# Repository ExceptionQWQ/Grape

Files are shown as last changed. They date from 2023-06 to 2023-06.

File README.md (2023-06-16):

# **基于树莓派的智能物料搬运小车的系统设计**

## ***一，研究背景***
>
>        在现代物流和制造业中，物料搬运是一个不可或缺的环节。传统的物料搬运通常依赖于人工操作或传统的机械设备，但这些方法存在着一些限制和挑战。人工操作可能受到工人疲劳、人力资源限制和效率低下的问题影响。传统机械设备则可能受到固定路线和复杂环境下的机动性限制。
>        然而，随着人工智能和自动化技术的快速发展，智能物料搬运小车作为一种新型的物流解决方案已经开始崭露头角。这些小车集成了先进的感知、规划和控制系统，能够自主地感知环境、规划最优路径并执行搬运任务。智能物料搬运小车的出现为物流和制造业带来了许多机遇和改进空间。

---

## ***二，设计目的***
>        物流和制造业是现代经济中至关重要的组成部分，而物料搬运作为物流过程中不可或缺的环节，对于企业的运营效率和竞争力起着至关重要的作用。传统的物料搬运方法往往面临着一系列的挑战，为了应对这些挑战，人工智能和自动化技术成为了物流行业关注的焦点。智能物料搬运小车作为一种新兴的物流解决方案，具备了自主感知、智能规划和高效执行的能力。通过利用先进的传感器技术、路径规划算法和控制系统，智能物料搬运小车能够准确感知环境、自主规划最优路径，并在复杂的物流环境中高效地执行搬运任务。  
>        此次个性化实践，我将重点研究智能物料搬运小车的零部件的选型、建模、设计以及制作过程。

---

## ***三，零件选型***

> 1. 麦克纳姆轮  
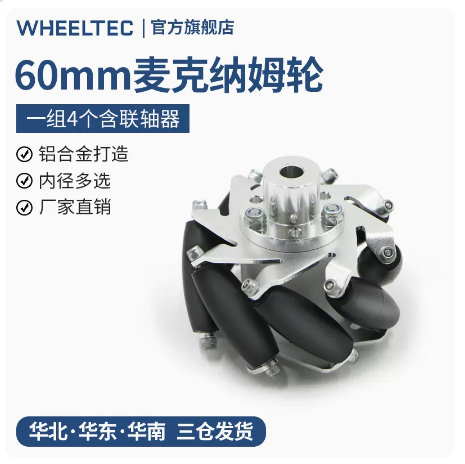
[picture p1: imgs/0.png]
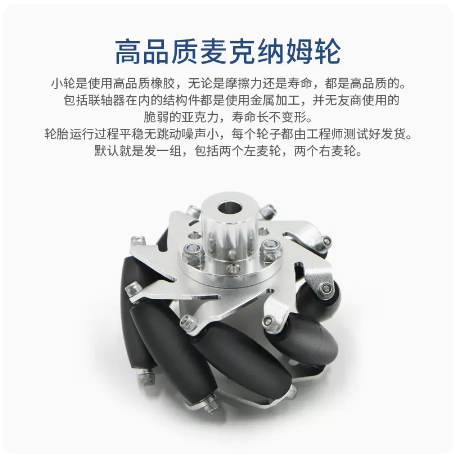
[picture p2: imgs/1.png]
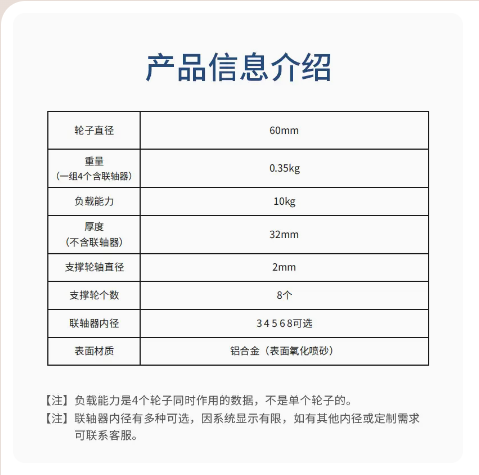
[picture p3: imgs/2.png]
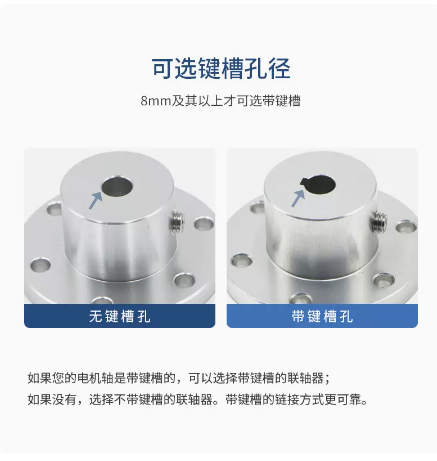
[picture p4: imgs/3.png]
>   
>    > 使用麦克纳姆轮作为智能物料搬运小车的轮胎具有以下优点：  
>    >    > 多向移动能力：麦克纳姆轮是一种特殊的全向轮，具有独特的轮胎结构和布局。它由多个斜向排列的轮辋组成，使得小车能够在不转向的情况下实现平稳的多向移动。这种设计使得小车可以自由地在水平和垂直方向上移动、旋转和平移，从而在狭小的空间中灵活操作和搬运物料。  
>    > 
>    >    > 卓越的机动性：麦克纳姆轮的布局和运动原理使得小车具有卓越的机动性。每个轮子都可以独立运动，无论是向前、向后、向左还是向右，都可以实现精确的控制。这种机动性使得小车能够轻松地避开障碍物、穿过狭窄的通道和转弯，提高了操作的灵活性和效率。  
>    > 
>    >    > 高精度定位：麦克纳姆轮的运动特性使得小车能够实现高精度的定位和操控。通过对每个轮子的独立控制，可以精确地调整和控制小车的位置和姿态。这种精度定位的能力对于准确搬运和定位物料非常重要，特别是在需要精细操作的环境中。
>
> 2. 电机驱动  
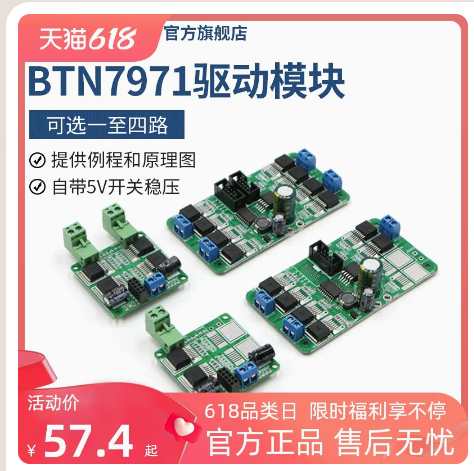
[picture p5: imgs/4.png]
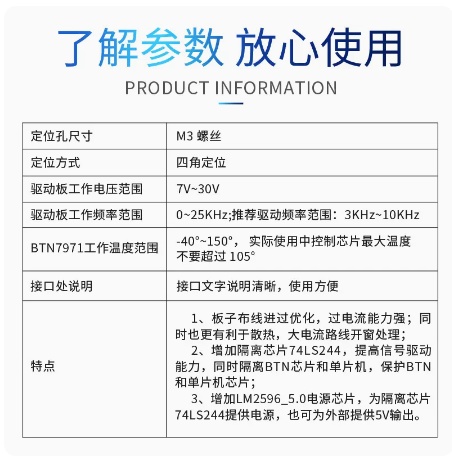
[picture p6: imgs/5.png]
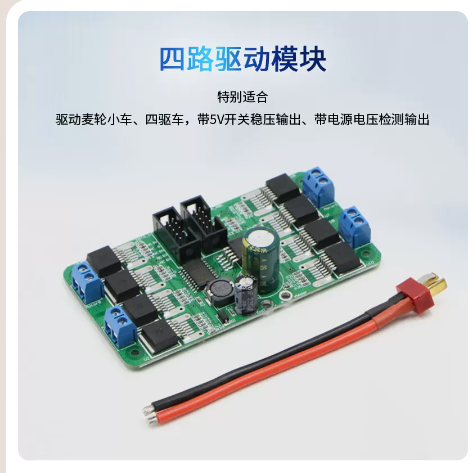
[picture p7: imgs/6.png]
> 
> 
>    > 这是一款可驱动大功率电机的电机驱动模块，具有大电流，高驱动的特点。
>
> 3. 调试下载器  
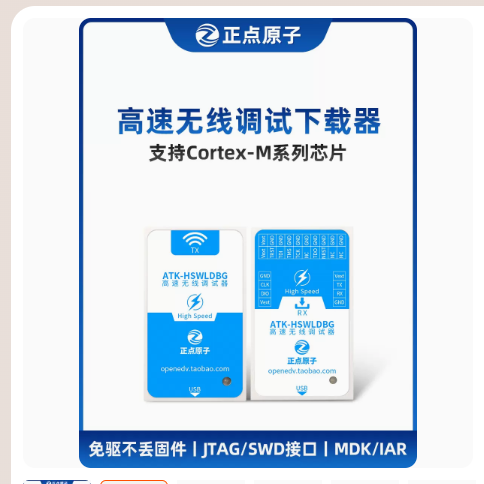
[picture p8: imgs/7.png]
> 
>    > 这款高速无线调试下载器支持仿真调试、程序下载、无线串口功能，提供20P标准JTAG借口和4P简化SWD接口，能够很大程度上帮助我调试小车。
>
> 4. 舵机  
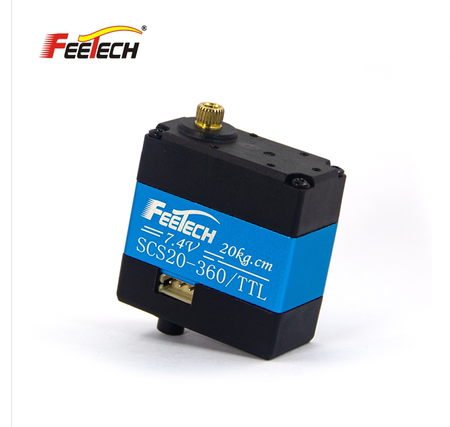
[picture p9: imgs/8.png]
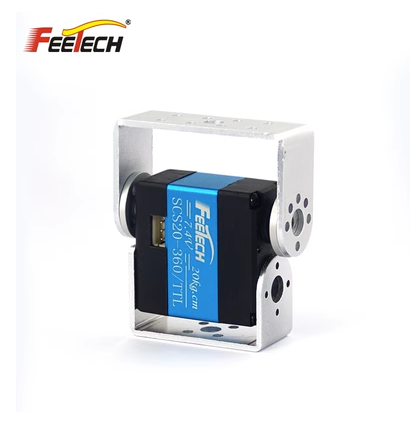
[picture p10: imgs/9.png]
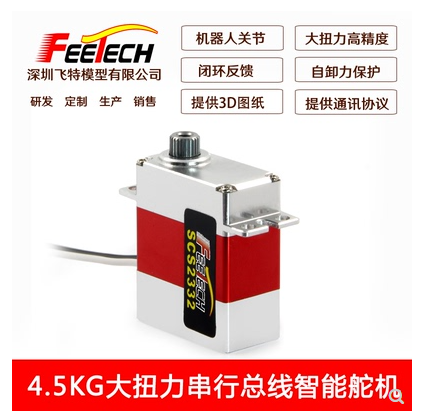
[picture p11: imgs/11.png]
> 
>    > 舵机采用飞特金属磁编码总线舵机，该产品具有以下特点，能够方便我们后期调试云台、机械臂、机械爪。  
>    >    > * 外壳采用CNC全铝合金，具有良好的导热性能。  
>    >    > * 全钢齿轮和轴承设计，强度更高，寿命更长。  
>    >    > * 采用空心杯电机作为动力源，具备无铁芯、转子、电感小、响应性好、效率高、体积小易取得大扭矩。  
>    >    > * 多圈大角度精准控制，最高精度下可以正负7圈绝对位置控制与反馈。  
>    >    > * 12位高精度无接触式磁编码传感器。  
>    >    > * 加速度启动与停止功能，可实现在行程过程中柔和运动，对齿轮有更好的保护作用。  
>    >    > * 支持4种工作模式，分别是位置模式、速度闭环电机模式、速度开环电机模式、步进模式。  
>    >    > * 一键校准中位，360度角度任意安装，非常方便安装，可提升生产效率和降低维护成本。  
>    >    > * 过载保护。  
>    >    > * 过热保护。  
>    >    > * 实时反馈。  
>    >    > * 角度限位。  
>    >    > * 最大扭矩限制。  
>    >    > * PID比例系统调节。  
>    >    > * 多个舵机串联控制。  
> 5. 打印耗材  
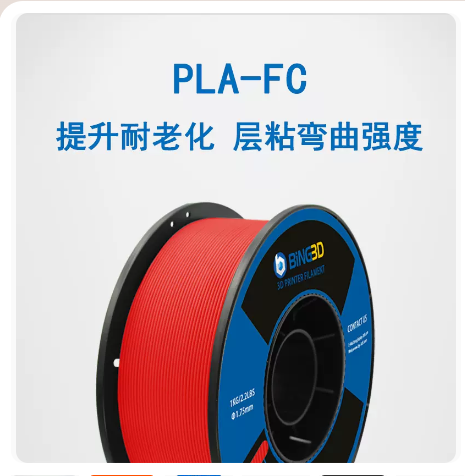
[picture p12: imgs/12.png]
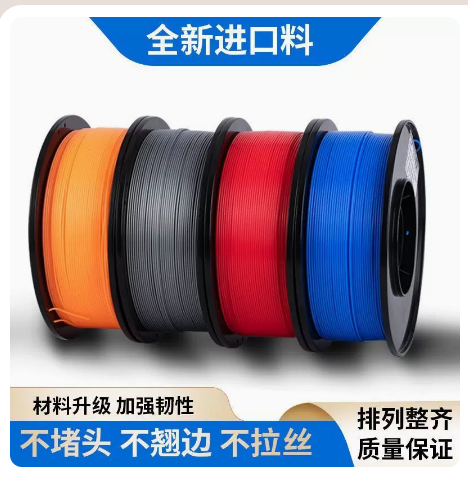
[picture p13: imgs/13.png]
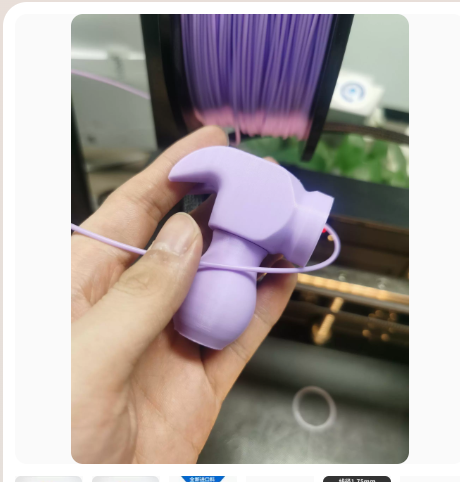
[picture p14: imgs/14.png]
> 
>    > 机械臂机械爪和外壳部分，我计划采用3D打印，我使用的必应PLA-FC材料，与传统PLA材料相比，PLA-FC的韧性与抗冲击强度更优异，使其打印成品具备的物理性能广泛应用于小批量打印工业件，并且它价格便宜，Raise3D官方1kg耗材需要199元，而必应只需要39元。
> 6. 碳纤维板  
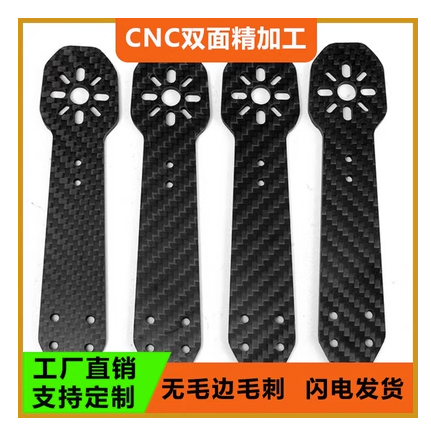
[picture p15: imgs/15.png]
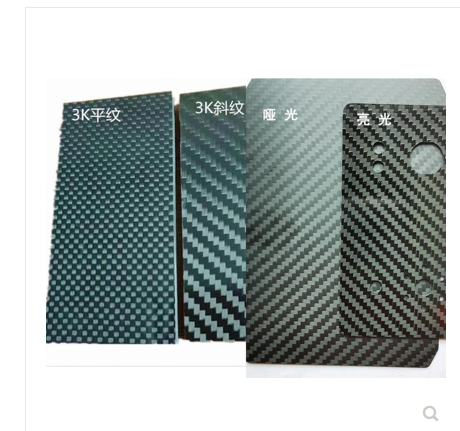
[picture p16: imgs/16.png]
> 
>    > 使用碳纤维版作为智能物料搬运小车的底盘具有轻量化、高强度和刚度、抗腐蚀性和耐久性、良好的振动和噪音阻尼、美观性和设计自由度等优点。这些优势使得碳纤维底盘成为一种理想的选择，能够提升小车的性能、稳定性和寿命，为智能物料搬运小车的应用带来更好的效果和体验。
> 7. 电源模块  
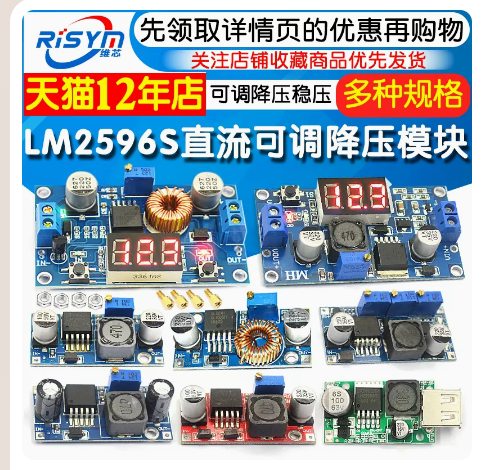
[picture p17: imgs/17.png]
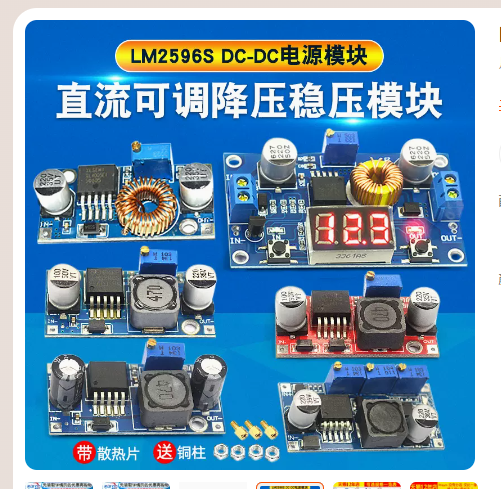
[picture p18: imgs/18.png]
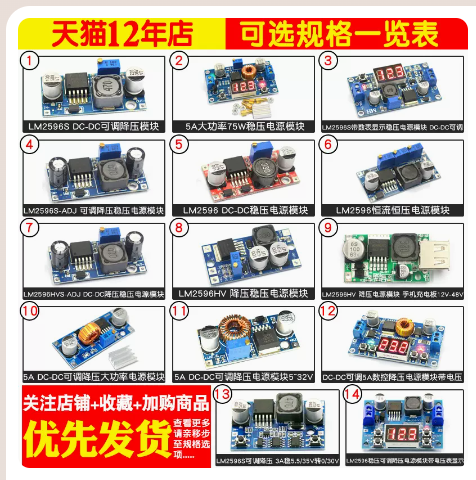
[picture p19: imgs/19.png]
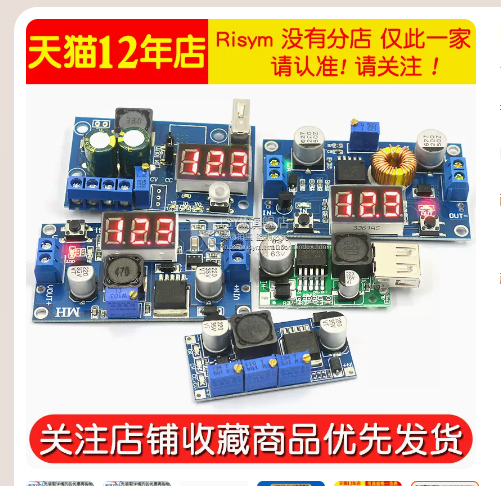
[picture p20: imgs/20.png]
> 
>    > 我计划采用3个5A大功率75W稳压电源模块，支持4～38V的宽电压输入范围，一块负责提供5V电压，给树莓派、单片机、模块供电，一块负责提供7.4V电压，给舵机供电，最后一块负责提供12V电压，给电机驱动供电。
> 8. 电池  
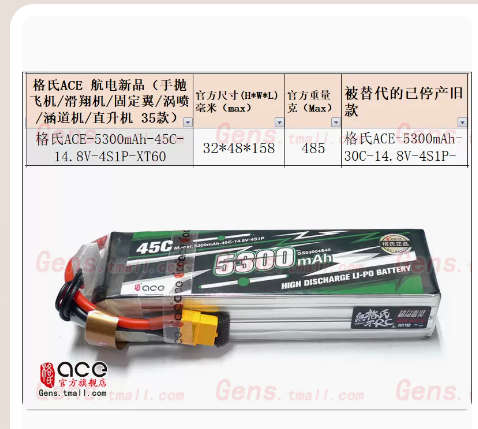
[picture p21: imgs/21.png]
> 
>    > 格氏5300mah 4s 14.8V 30C电池，持续放电159A（瞬间318A），动力强劲。
> 9. 电机  
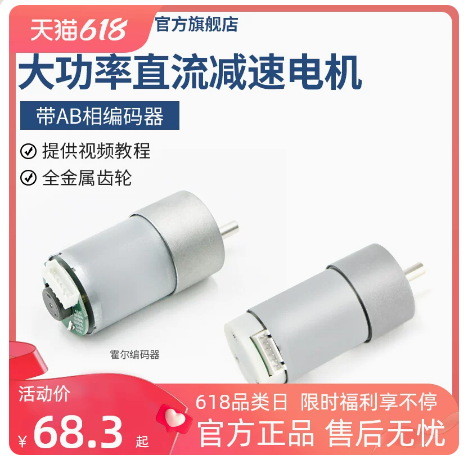
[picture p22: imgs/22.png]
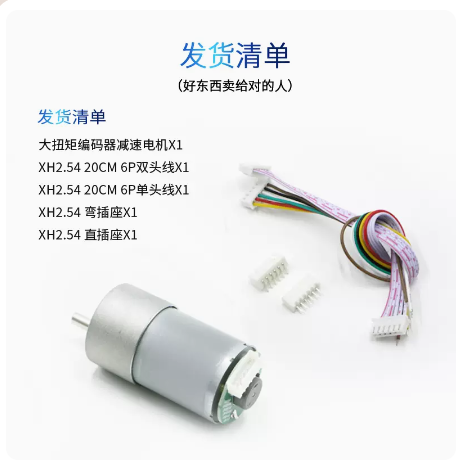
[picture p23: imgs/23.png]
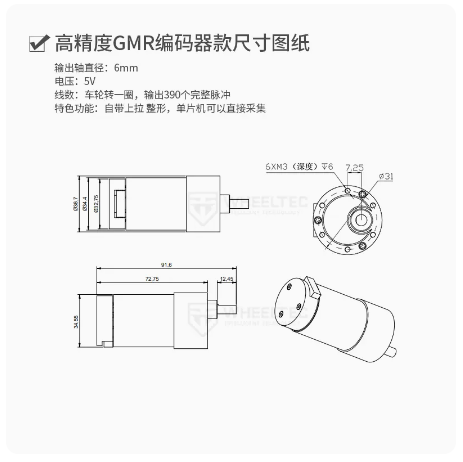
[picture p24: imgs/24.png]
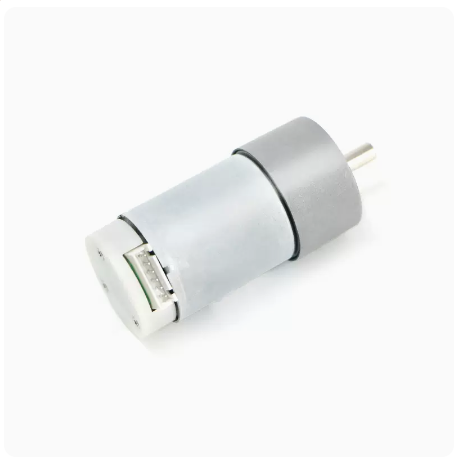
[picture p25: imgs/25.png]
> 
>    > WHEEL TEC的MG540大功率直流减速电机（高精度GMR编码器款），GMR编码器是霍尔编码器精度的38倍，在低速情况下表现优异。
> 10. 激光雷达  
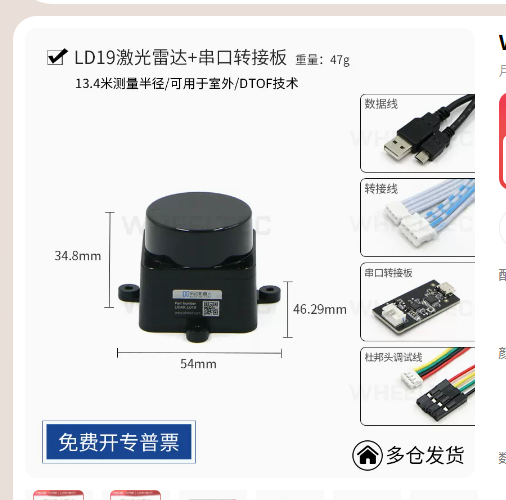
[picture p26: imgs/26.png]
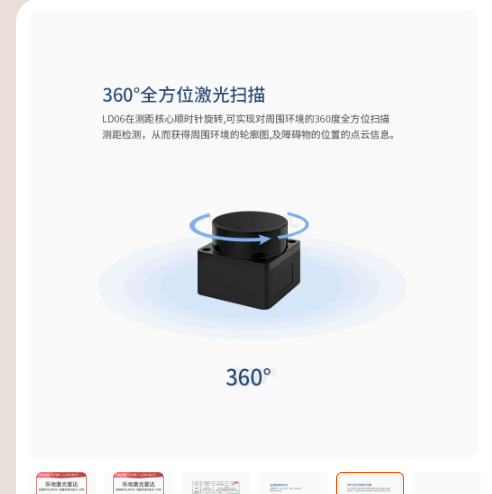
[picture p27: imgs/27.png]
> 
>     > 基于TOF原理的LD19激光雷达可抗强光，可有效避免强光照干扰，可抵抗30000Lux的强光环境，可实现室内外高频高精度的距离测量及精准建图。LD19测量半径可以达到13.4m，扫描频率10HZ，采样频率4500次/s。内置无刷电机相比传统的有刷电机具有更高的效能，寿命更长。
> 11. 深度相机  
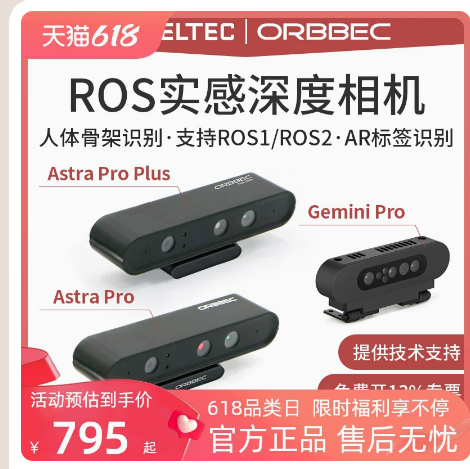
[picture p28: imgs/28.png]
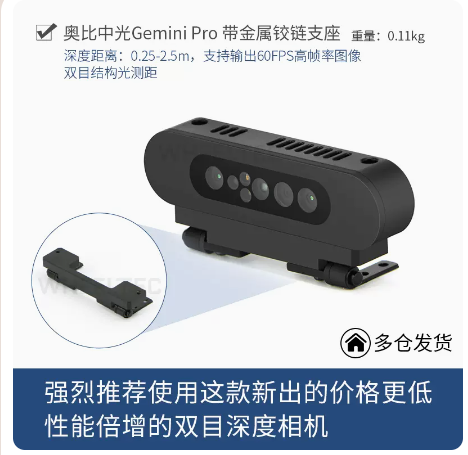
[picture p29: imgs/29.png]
> 
>     > Gemini Pro相机基于双目结构光（红外投影）测距原理，高达8米深度测距，特别适合机器人三维环境重建，提高环境建模效率，测量盲区低至0.25米，特别适用于近距离测量，广泛应用于机器人末端执行器定位等应用场景。Gemini Pro使用了D435i等国际知名相机惯用的成熟双目架构，支持在室外场景使用。它带有可以自由旋转的铰链支座，安装简单，方便调整相机视角，金属加工，更加稳固耐用。
> 12. 树莓派  
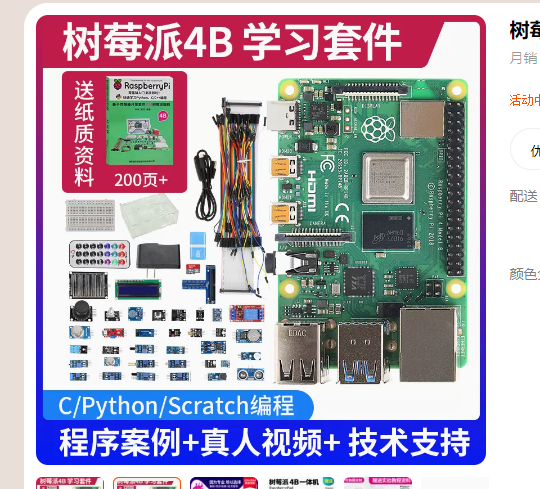
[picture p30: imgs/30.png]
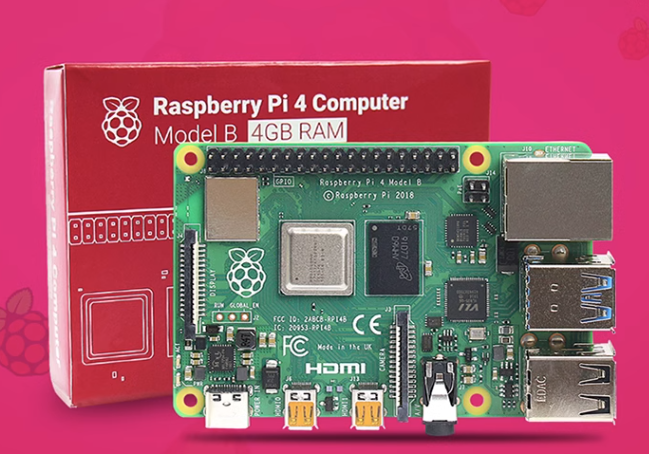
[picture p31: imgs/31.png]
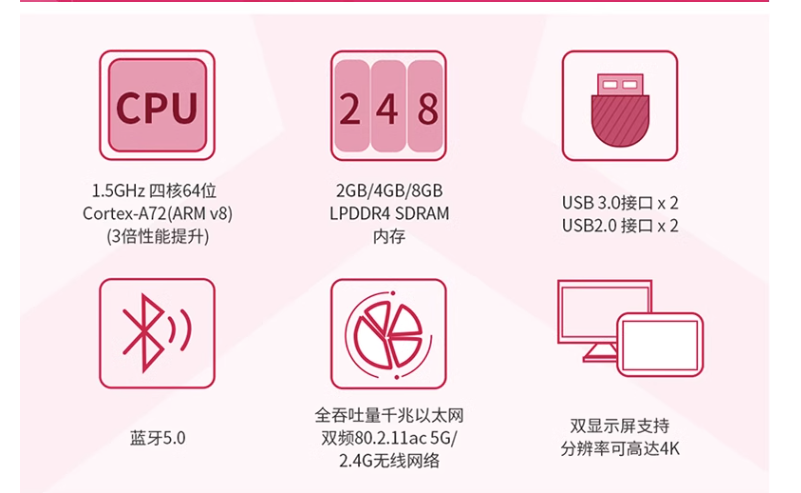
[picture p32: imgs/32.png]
> 
>     > 树莓派是一款基于ARM架构的单板计算机，具有较强的计算和处理能力。它采用高性能的处理器和足够的内存，能够处理复杂的算法和任务，支持实时控制和决策。这使得树莓派能够实现复杂的路径规划、感知处理和决策算法，提高智能物料搬运小车的智能化水平。树莓派提供了丰富的接口和扩展插槽，包括GPIO、USB、HDMI等接口，可以连接各种传感器、执行器和外部设备。这使得树莓派可以方便地与硬件组件进行通信和控制，实现与激光雷达、下位机、摄像头等设备的无缝集成。树莓派具有广泛的开发者社区和大量的开源软件资源，提供了丰富的开发环境和工具支持。开发者可以利用Python、C++等编程语言进行开发，并借助各种开源库和工具快速实现功能。这降低了开发门槛，加快了系统开发和调试的速度。
> 13. 无线网卡  
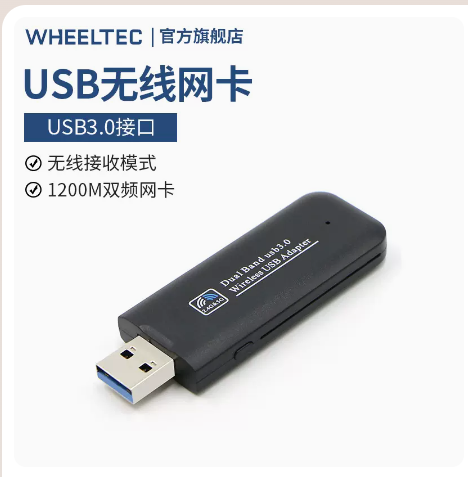
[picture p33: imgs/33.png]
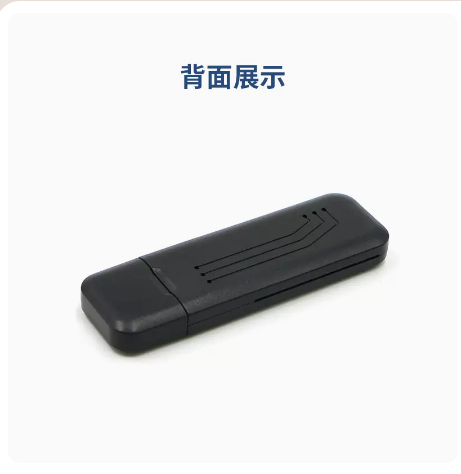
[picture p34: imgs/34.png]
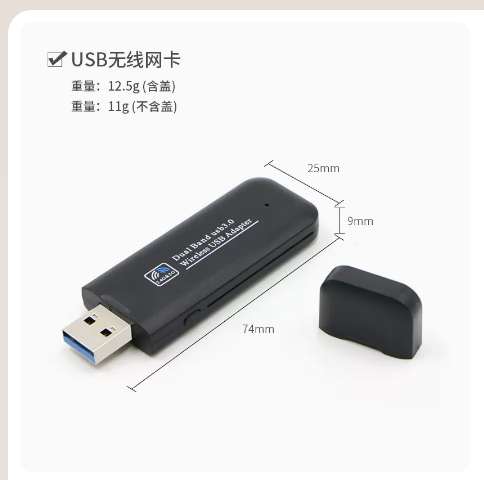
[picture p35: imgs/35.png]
> 
>     > 鉴于树莓派自带的无线能力弱，我外置了一款USB3.0的无线网卡。
> 14. USB摄像头  
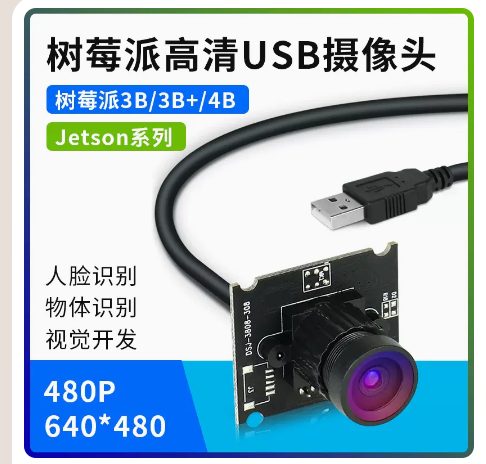
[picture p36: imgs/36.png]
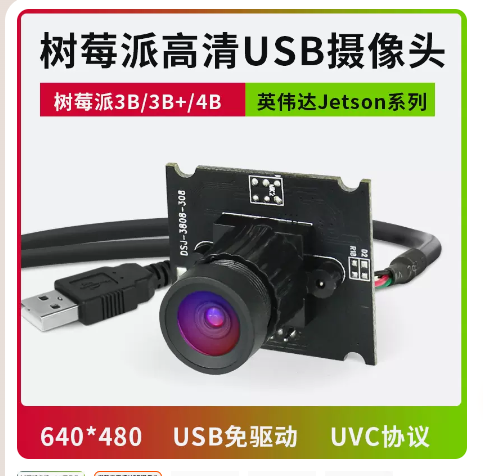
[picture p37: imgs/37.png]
> 
>     > 末端执行器采用便宜的USB摄像头，可以实现物料识别与定位。
> 15. STM32  
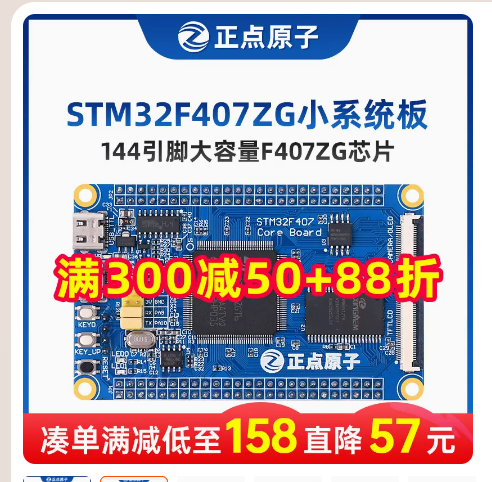
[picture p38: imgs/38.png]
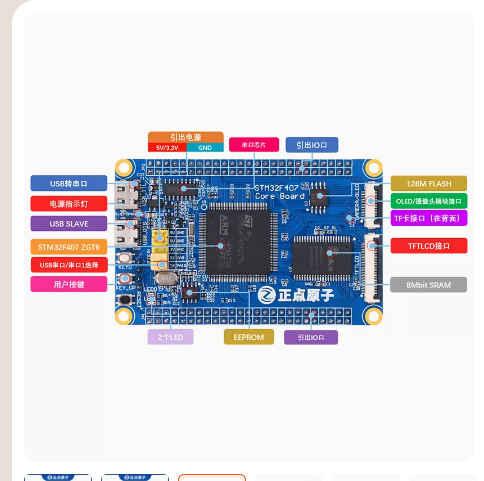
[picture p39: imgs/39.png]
> 
>     > 采用高性能的STM32F407最小系统板作为下位机，实现运动控制算法。
> 16. 惯性导航模块  
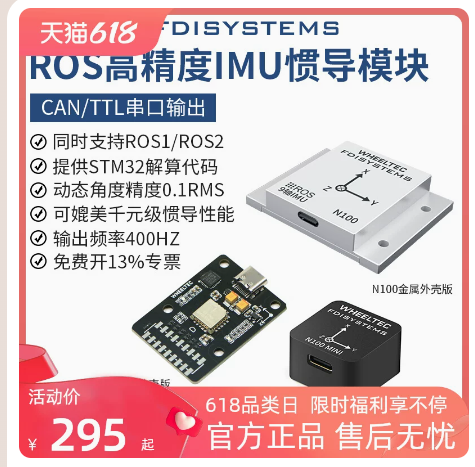
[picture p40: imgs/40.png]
> 
>     > N100惯导模块具备丰富的数据输出，支持三轴加速度、三轴陀螺仪、三轴磁力计、三轴欧拉角、四元数、方向余弦矩阵、速度、位置输出，自带卡尔曼融合算法。

---

## ***四，PCB板设计***

> 1. 绘制原理图
>    > * STM32F407  
>    >    >  
>    > * 电机接口  
>    >    >   
>    > * 电机驱动接口  
>    >    >   
>    > * 外部传感器接口  
>    >    >   
> 2. 绘制PCB
>    >  

---

## ***四，零件建模***
> 1. 惯性导航模块  
>    > 
> 2. 37电机支架  
>    > 
> 3. DC电源模块 
>    > 
> 4. SCS125舵机  
>    > 
> 5. SCS2332舵机  
>    > 
> 6. STS3020舵机  
>    > 
> 7. USB摄像头  
>    > 
> 8. 云台  
>    > 
> 9. 舵机支架  
>    >  
> 10. BTN7971四路驱动  
>     > 
> 11. 舵盘  
>     >  
> 12. TTL信号转换板  
>     > 
> 13. 机械臂  
>     > 
> 14. 树莓派  
>     > 
> 15. 联轴器  
>     > 
> 16. 深度相机  
>     > 
> 17. 激光雷达  
>     > 
> 18. 机械爪  
>     > 
> 19. 电机  
>     > 
> 20. 船型开关  
>     > 
> 21. 散热风扇  
>     > 
> 22. 麦克纳姆轮  
>     > 

----

## ***五，小车结构设计***

> * 设计底盘2  
>     > 
> * 安装4个直流减速电机  
>     > 
> * 安装4个麦克纳姆轮  
>     > 
> * 设计底盘1  
>     > 
> * 装配底盘1  
>     > 
> * 给底盘1开4个矩形孔  
>     > 
> * 设计底盘3  
>     > 
> * 装配底盘3  
>     > 
> * 开一个放置云台的孔  
>     > 
> * 放置云台  
>     > 
> * 设计放置电池的位置  
>     > 
> * 放置电池  
>     > 
> * 设计放置电机驱动板的位置  
>     > 
> * 放置电机驱动板  
>     > 
> * 设计放置电源模块的位置  
>     > 
> * 放置电源模块  
>     >   
> * 放置2个激光雷达  
>     >   
> * 放置TTL信号转换板  
>     >   
> * 放置惯性导航模块  
>     >   
> * 放置树莓派  
>     >   
> * 放置深度相机  
>     >   
> * 放置下位机控制板  
>     >   
> * 完成外壳1设计  
>     >   
> * 完成外壳2设计  
>     > 
>     > 
>     >   
> * 设计机械臂  
>     > 
>     > 
>     > 
>     >   
> * 放置机械爪  
>     >   
> * 完成运动分析  
>     >   

## ***六，物流小车组装***


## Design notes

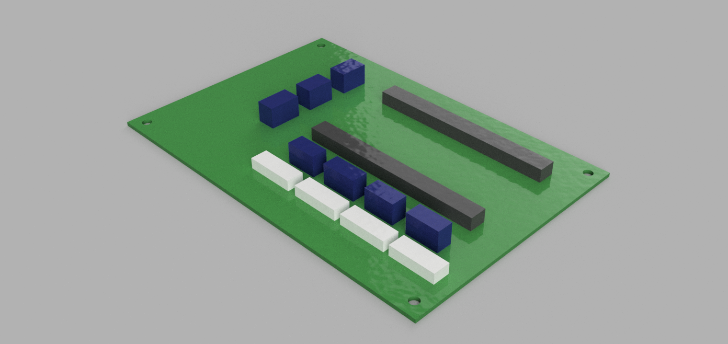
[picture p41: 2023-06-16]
imgs/渲染/pcb v3.png

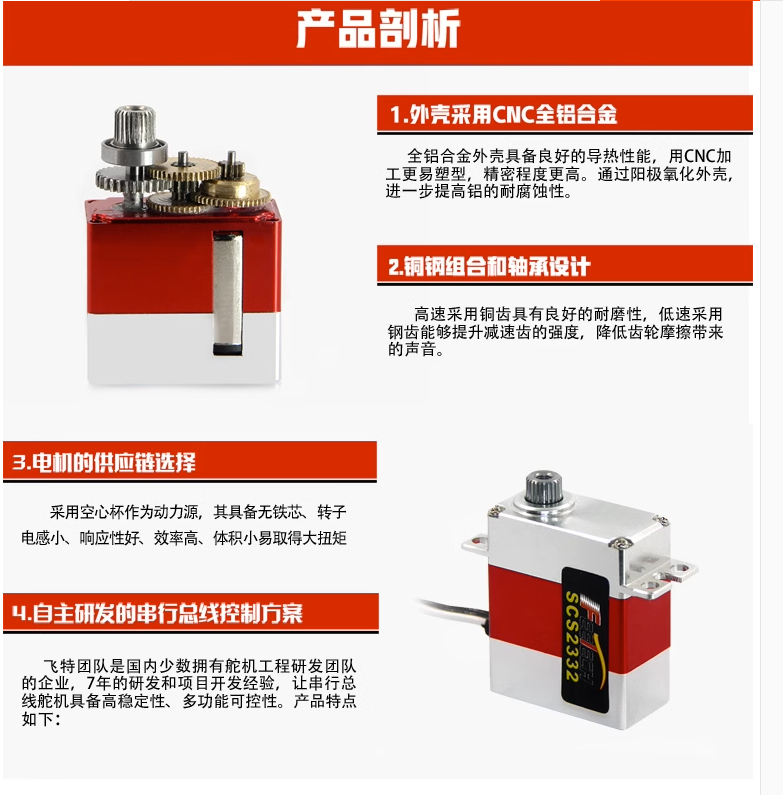
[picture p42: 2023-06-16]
imgs/选型/舵机/屏幕截图 2023-06-11 194429.png

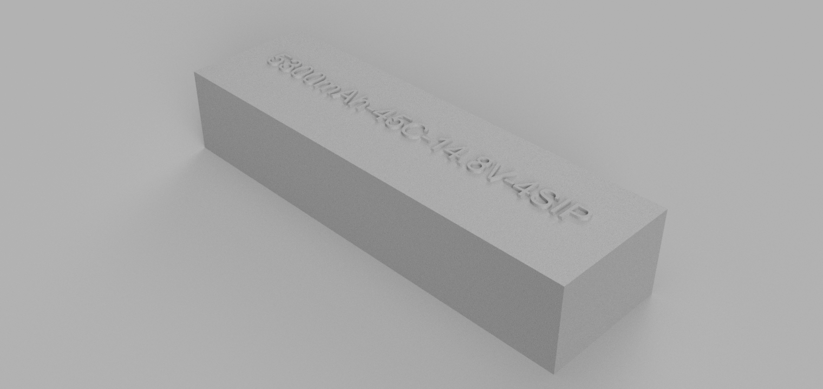
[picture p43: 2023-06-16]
imgs/渲染/格氏电池 v2.png

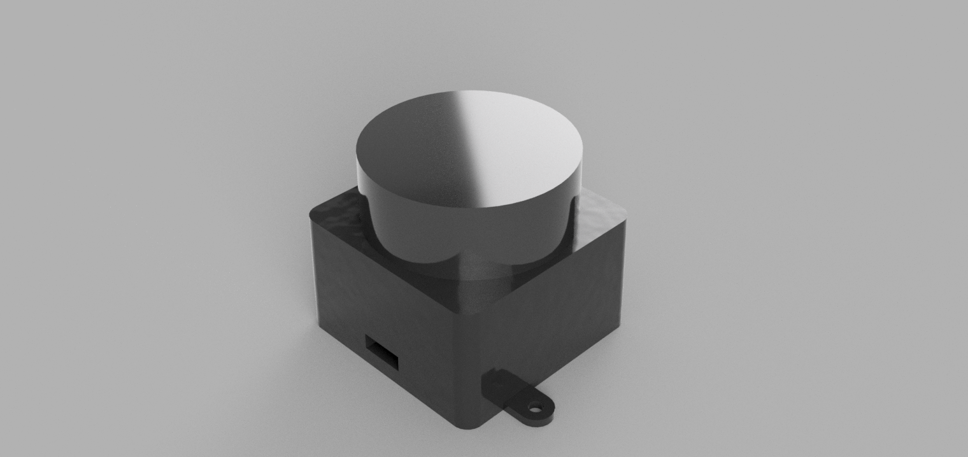
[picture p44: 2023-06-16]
imgs/渲染/LD19激光雷达 v2.png

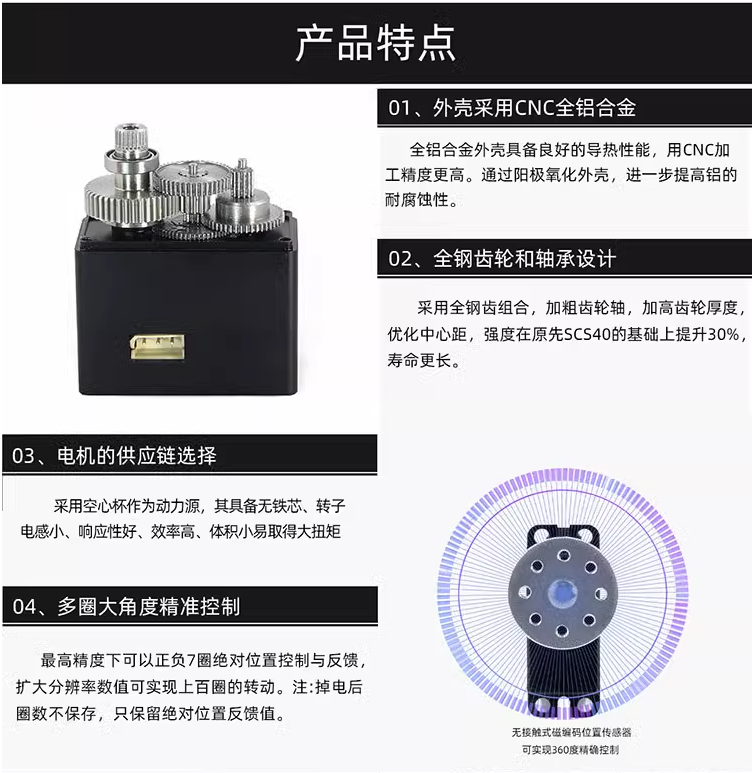
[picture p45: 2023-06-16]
imgs/选型/舵机/屏幕截图 2023-06-11 194345.png

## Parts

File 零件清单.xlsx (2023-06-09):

名称 | 型号 | 单价 | 数量 | 购买链接 | 备注
麦克纳姆轮 | 直径60mm 安装孔径6mm不带键槽*4个 | 219 | 1 | https://m.tb.cn/h.UCVZ0lf?tk=cFMZdqj3pVL
MG540大扭矩编码器减速电机 | 高精度GMR编码器款+支架 | 102.8 | 4 | https://m.tb.cn/h.UCVbmNc?tk=RwkEdqj4uUE
多路BTN7971 | 四路驱动模块 | 218 | 1 | https://m.tb.cn/h.UCV1f7k?tk=JmL6dqjflCD
惯导模块IMU | N100带金属外壳 | 388 | 1 | https://m.tb.cn/h.UBOkcWQ?tk=PZUZdqj5E9F
DC-DC直流可调降压稳压电源 | 5A大功率75W稳压电源模块 | 26.06 | 3 | https://m.tb.cn/h.UyKMBMc?tk=ESjidqjgyh9
船型开关 | KCD4 4脚2档红灯 铜脚（2个） | 2.67 | 1 | https://m.tb.cn/h.UBOlMuA?tk=lD7qdqj6hWA
格氏ACE 新航电池 | 5300mAh 45C 4S xt60 | 428 | 1 | https://m.tb.cn/h.UBON5C1?tk=DiTSdqjhGIg
信号转换板 | 宝蓝色 信号转化板 | 40 | 1 | https://m.tb.cn/h.UBOn7Pn?tk=YumOdqjhIBK
双轴舵机 | 蓝色 ST3020带支架 | 120 | 3 | https://m.tb.cn/h.UBOn7Pn?tk=YumOdqjhIBK
金属40kg360度单轴舵机 | 黑色 ST-3046-C001 单轴 | 448 | 1 | https://m.tb.cn/h.UCVerpt?tk=kL5Bdqj7Olc
飞特4.5kg小舵机 | SCS2332/270度转动 | 148 | 2 | https://m.tb.cn/h.UCBpQ1x?tk=PbcPdqjidTB
正点原子STM32F407ZGT6小系统板 | 焊排针 | 218 | 1 | https://m.tb.cn/h.UBOLk6I?tk=8LTGdqj8JmE
正点原子高速无线调试器 | 发射端+大接收端 | 368 | 1 | https://m.tb.cn/h.UBOpNEC?tk=zPCldqj8AF6
树莓派4B | 树莓派4B/8G单独主板 | 1059 | 1 | https://m.tb.cn/h.UBOpH1S?tk=w1OHdqj8wiv
树莓派jetson免驱USB摄像头 | USB摄像头 | 49 | 1 | https://m.tb.cn/h.UCBJ9R2?tk=QJ5EdqjQE0O
树莓派4代CPU散热器 | 卧式散热器（白色） | 105 | 1 | https://m.tb.cn/h.UyKGgFU?tk=PCMfdqj9McP
无线网卡千兆高速免驱动 | USB无线网卡 | 79 | 1 | https://m.tb.cn/h.UCVTKkr?tk=127odqj9HT6
激光雷达 | LD19激光雷达+串口转接板 | 549 | 2 | https://m.tb.cn/h.UCVTHbn?tk=D3pbdqjkewS
深度相机摄像头 | 【双目结构光】奥比中光Gemini Pro | 1190 | 1 | https://m.tb.cn/h.UyKFkdo?tk=C3BhdqjkLWe
必应3d打印耗材pla-f复合材料 | PLA-FC 浅紫色 1KG | 39 | 5 | https://m.tb.cn/h.UBOI5r3?tk=oOl1dqjlP1W
华秋PCB打样 | 最终价格请先联系客服报价 | 92 | 1 | https://m.tb.cn/h.UCV6yi7?tk=EZppdqjlV4G
碳纤维板加工 | 黑色/平纹/哑光 | 700 | 1 | https://m.tb.cn/h.UyKExnh?tk=LEaZdqjOYlh
BB响 | BX100 低压报警器 | 7.2 | 1 | https://m.tb.cn/h.UyKwnkc?tk=DJCVdqjlwpF

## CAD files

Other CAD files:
3D模型/37GB电机支架 v2.f3d
3D模型/9轴IMU v2.f3d
3D模型/DC模块 v2.f3d
3D模型/LD19激光雷达 v2.f3d
3D模型/MG540直流减速电机（GMR） v8.f3d
3D模型/SCS125舵机 v2.f3d
3D模型/SCS2332舵机 v2.f3d
3D模型/STS3020双轴舵机 v1.f3d
3D模型/USB摄像头 v2.f3d
3D模型/pcb v3.f3d
3D模型/云台 v10.f3z
3D模型/双轴舵机支架1 v3.f3d
3D模型/双轴舵机支架2 v2.f3d
3D模型/四路驱动模块 v2.f3d
3D模型/大臂 v4.f3d
3D模型/小臂 v3.f3d
3D模型/小舵机舵盘 v2.f3d
3D模型/总线舵机信号转换版 v2.f3d
3D模型/显示屏 v2.f3d
3D模型/标准舵机 v4.f3d
3D模型/树莓派 v2.f3d
3D模型/格氏电池 v2.f3d
3D模型/法兰联轴器 v3.f3d
3D模型/深度相机 v2.f3d
3D模型/爪子 v6.f3z
3D模型/爪子右 v4.f3d
3D模型/爪子左 v4.f3d
3D模型/船型开关（红） v4.f3d
3D模型/船型开关（绿） v3.f3d
3D模型/金属舵盘 v4.f3d
3D模型/风扇 v1.f3d
3D模型/麦克纳姆轮A v5.f3d
3D模型/麦克纳姆轮B v9.f3d

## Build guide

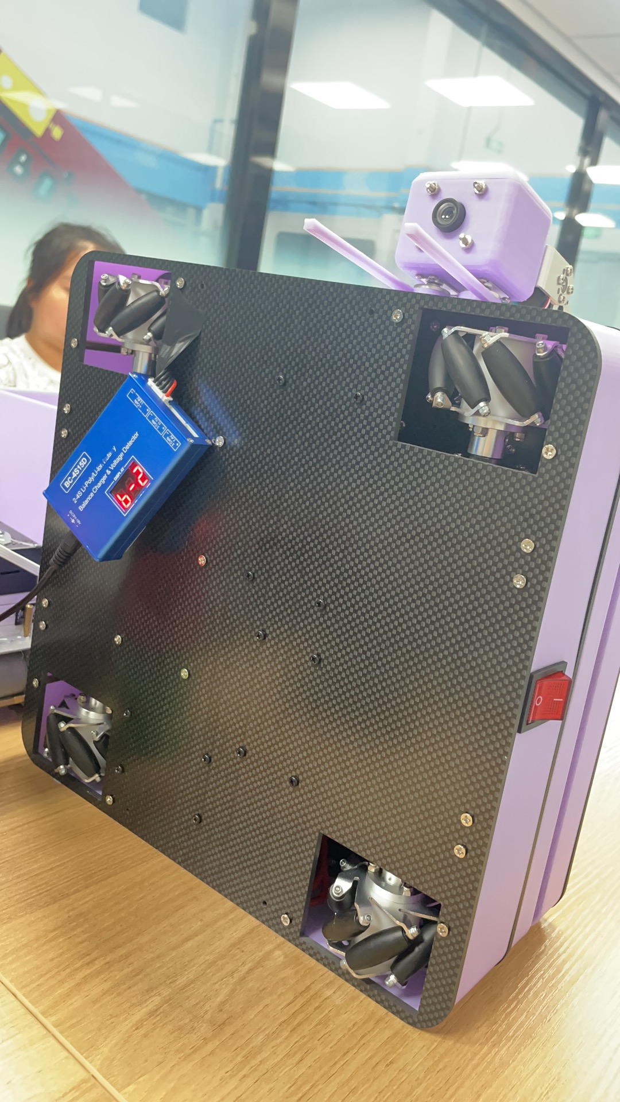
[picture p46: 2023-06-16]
imgs/组装/D7C8EA0B-1885-40CE-9DB8-34D4BC48AEBF.jpeg

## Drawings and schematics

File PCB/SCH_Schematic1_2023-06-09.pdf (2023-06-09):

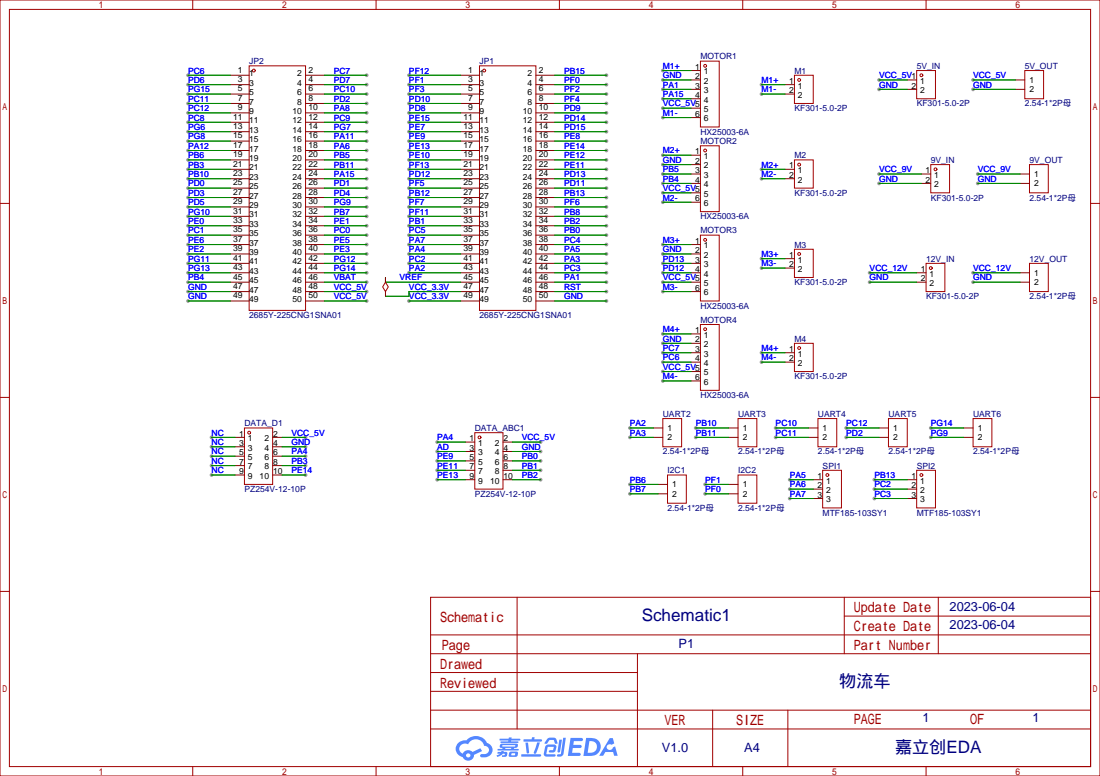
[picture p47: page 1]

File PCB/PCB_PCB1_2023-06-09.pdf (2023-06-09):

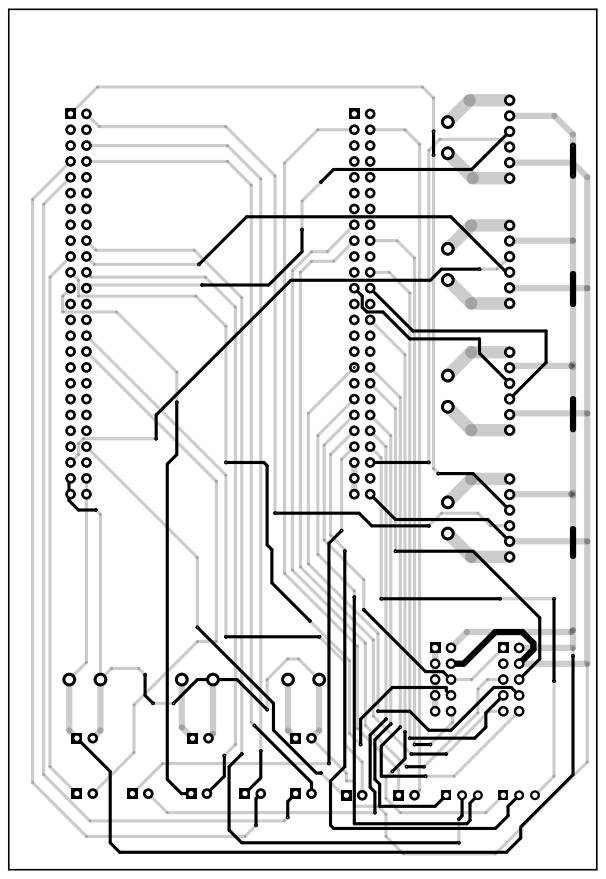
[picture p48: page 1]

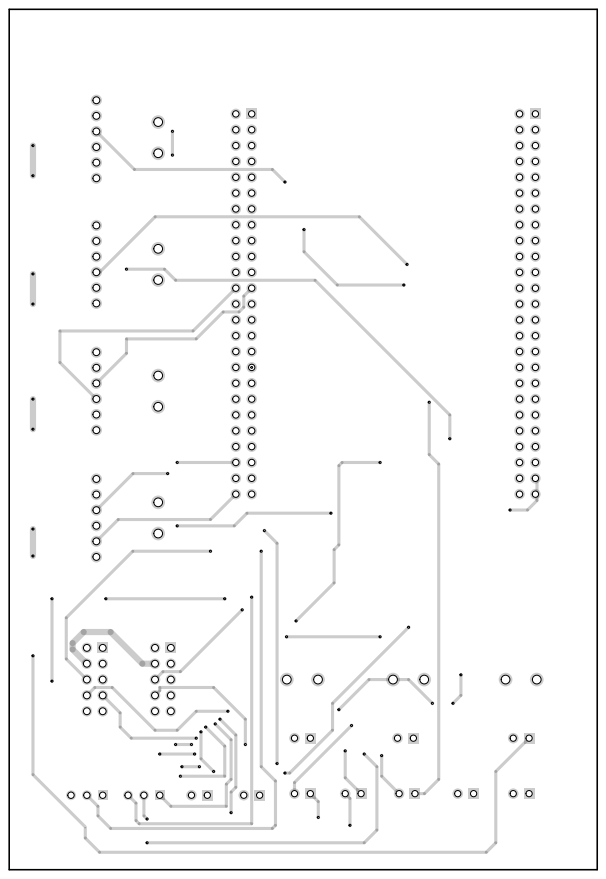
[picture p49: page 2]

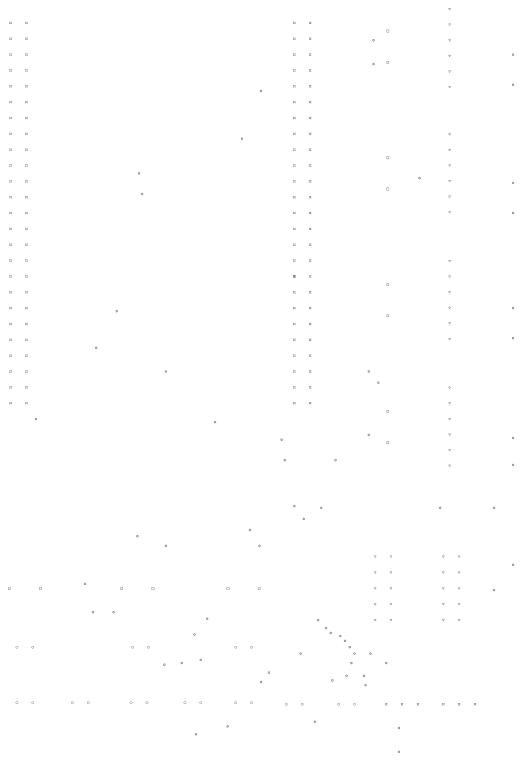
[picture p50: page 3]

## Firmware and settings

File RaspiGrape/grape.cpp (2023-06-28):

#include "grape.h"
#include "robot.h"
#include "servo.h"



struct ArmInfo
{
    double len;
    double radian;
};


using ArmList = std::vector<ArmInfo>;

ArmList SolveArm3DH(double len1, double len2, double len3, double xPos, double yPos)
{
    if (fabs(xPos) < 0.001) xPos = 0.001;
    double len = std::sqrt(std::pow(xPos, 2) + std::pow(yPos, 2));
    if (len > len1 + len2) return ArmList{}; //无解
    double r4 = std::acos((std::pow(len1, 2) + std::pow(len2, 2) - std::pow(len, 2)) / (2 * len1 * len2));
    double r5 = std::atan(yPos / xPos);
    if (xPos < 0 && yPos > 0) {
        r5 += PI;
    }
    std::cout << r4 << std::endl;
    double r2 = r4 - PI;
    double r3 = std::asin(len2 * std::sin(r4) / len);
    double r1 = r3 + r5;
    return ArmList{{len1, r1}, {len2, r2}, {len3, -(r1 + r2)}};
}

// SERVO_TAG_L1 = 2, //0-3050, 90-2050
//     SERVO_TAG_L2 = 3, //0-2150, 90-3150
//     SERVO_TAG_L3 = 4, //0-1950, 90-2950
//     SERVO_TAG_ClawL = 5, //0-, 90-
//     SERVO_TAG_ClawR = 6, //0-, 90-


void SetL1Angle(double angle)
{
    std::cout << "l1: " << angle << std::endl;
    if (angle < 0 || angle > 150) return ;
    int pos = 3050;
    double add = 1000.0 / 90.0 * angle;
    pos += -add;
    SetServoPos(SERVO_TAG_L1, pos, 800);
}

void SetL2Angle(double angle)
{
    std::cout << "l2: " << angle << std::endl;
    if (angle < -150 || angle > 90) return ;
    int pos = 2150;
    double add = 1000.0 / 90.0 * angle;
    pos += add;
    SetServoPos(SERVO_TAG_L2, pos, 800);
}

void SetL3Angle(double angle)
{
     std::cout << "l3: " << angle << std::endl;
    if (angle < -90 || angle > 90) return ;
    int pos = 1950;
    double add = 1000.0 / 90.0 * angle;
    pos += add;
    SetServoPos(SERVO_TAG_L3, pos, 800);
}


int main()
{
    Robot_Init();
    Robot_Start();
    Servo_Init();
    Servo_Start();

    sleep(1);

    SetL1Angle(0);
    SetL2Angle(0);
    SetL3Angle(0);
    UpdateServoPos();

    sleep(3);

    double len1 = 165, len2 = 185, len3 = 55;
    double xPos = 340, yPos = 0;
    for (int i = 0; i < 80; ++i) {
        xPos -= 1;
        ArmList armList = SolveArm3DH(len1, len2, len3, xPos, yPos);
        if (armList.size() != 0) {
            SetL1Angle(180 / PI * armList[0].radian);
            SetL2Angle(180 / PI * armList[1].radian);
            SetL3Angle(180 / PI * armList[2].radian);
            UpdateServoPos();
        }
        usleep(10000);
    }
    for (int i = 0; i < 160; ++i) {
        yPos += 1;
        ArmList armList = SolveArm3DH(len1, len2, len3, xPos, yPos);
        if (armList.size() != 0) {
            SetL1Angle(180 / PI * armList[0].radian);
            SetL2Angle(180 / PI * armList[1].radian);
            SetL3Angle(180 / PI * armList[2].radian);
            UpdateServoPos();
        }
        usleep(10000);
    }
    for (int i = 0; i < 130; ++i) {
        xPos -= 1;
        ArmList armList = SolveArm3DH(len1, len2, len3, xPos, yPos);
        if (armList.size() != 0) {
            SetL1Angle(180 / PI * armList[0].radian);
            SetL2Angle(180 / PI * armList[1].radian);
            SetL3Angle(180 / PI * armList[2].radian);
            UpdateServoPos();
        }
        usleep(10000);
    }


    // SetServoPos(SERVO_TAG_YUNTAI, 1450, 300);
    // SetServoPos(SERVO_TAG_L1, 3050, 300);
    // SetServoPos(SERVO_TAG_L2, 2150, 300);
    // SetServoPos(SERVO_TAG_L3, 1950, 300);
    // UpdateServoPos();

    while (true) {
        sleep(1);
        GetServoPos(SERVO_TAG_YUNTAI);
        GetServoPos(SERVO_TAG_L1);
        GetServoPos(SERVO_TAG_L2);
        GetServoPos(SERVO_TAG_L3);
        GetServoPos(SERVO_TAG_ClawL);
        GetServoPos(SERVO_TAG_ClawR);

        std::cout << "yuntai: " << servoInfo.yuntaiPos << std::endl;
        std::cout << "l1: " << servoInfo.l1Pos << std::endl;
        std::cout << "l2: " << servoInfo.l2Pos << std::endl;
        std::cout << "l3: " << servoInfo.l3Pos << std::endl;
        std::cout << "clawL: " << servoInfo.clawLPos << std::endl;
        std::cout << "clawR: " << servoInfo.clawRPos << std::endl;
        std::cout << "#############################################" << std::endl;
    }
    

    while (true) {
        char ch;
        std::cin >> ch;
        double speed;
        switch (ch) {
            case 'x':
                std::cin >> speed;
                Robot_MoveX(speed);
            break;
            case 'y':
                std::cin >> speed;
                Robot_MoveY(speed);
            break;
            case 'z':
                std::cin >> speed;
                Robot_MoveZ(speed);
            break;
            case 's':
                Robot_Stop();
            break;


            default:

            break;
        }
    }

    return 0;
}

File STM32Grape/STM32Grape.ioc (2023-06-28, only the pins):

Mcu.UserName=STM32F407ZGTx
PA1.Signal=S_TIM2_CH2
PA10.Signal=USART1_RX
PA13.Signal=SYS_JTMS-SWDIO
PA14.Signal=SYS_JTCK-SWCLK
PA15.Signal=S_TIM2_CH1_ETR
PA4.GPIO_Label=MOTOR_EN
PA4.Signal=GPIO_Output
PA9.Signal=USART1_TX
PB0.GPIO_Label=MOTOR1_DIRECTION
PB0.Signal=GPIO_Output
PB1.GPIO_Label=MOTOR2_DIRECTION
PB1.Signal=GPIO_Output
PB2.GPIO_Label=MOTOR3_DIRECTION
PB2.Signal=GPIO_Output
PB3.GPIO_Label=MOTOR4_DIRECTION
PB3.Signal=GPIO_Output
PB4.Signal=S_TIM3_CH1
PB5.Signal=S_TIM3_CH2
PC6.Signal=S_TIM8_CH1
PC7.Signal=S_TIM8_CH2
PD12.Signal=S_TIM4_CH1
PD13.Signal=S_TIM4_CH2
PE11.Signal=S_TIM1_CH2
PE13.Signal=S_TIM1_CH3
PE14.Signal=S_TIM1_CH4
PE9.Signal=S_TIM1_CH1
PH0-OSC_IN.Signal=RCC_OSC_IN
PH1-OSC_OUT.Signal=RCC_OSC_OUT

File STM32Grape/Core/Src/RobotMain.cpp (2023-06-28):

#include "RobotMain.h"


RDK::EncodingMotor encodingMotor1;
RDK::EncodingMotor encodingMotor2;
RDK::EncodingMotor encodingMotor3;
RDK::EncodingMotor encodingMotor4;
RDK::MecanumMotion mecanumMotion;


void Motor1Callback(double pwm)
{
    if (pwm > 0) {
        __HAL_TIM_SET_COMPARE(&htim1, TIM_CHANNEL_1, pwm);
        HAL_GPIO_WritePin(MOTOR1_DIRECTION_GPIO_Port, MOTOR1_DIRECTION_Pin, GPIO_PIN_RESET);
    } else if (pwm < 0) {
        __HAL_TIM_SET_COMPARE(&htim1, TIM_CHANNEL_1, 1000 + pwm);
        HAL_GPIO_WritePin(MOTOR1_DIRECTION_GPIO_Port, MOTOR1_DIRECTION_Pin, GPIO_PIN_SET);
    } else {
        __HAL_TIM_SET_COMPARE(&htim1, TIM_CHANNEL_1, 0);
        HAL_GPIO_WritePin(MOTOR1_DIRECTION_GPIO_Port, MOTOR1_DIRECTION_Pin, GPIO_PIN_RESET);
    }
}

void Motor2Callback(double pwm)
{
    if (pwm > 0) {
        __HAL_TIM_SET_COMPARE(&htim1, TIM_CHANNEL_2, pwm);
        HAL_GPIO_WritePin(MOTOR2_DIRECTION_GPIO_Port, MOTOR2_DIRECTION_Pin, GPIO_PIN_RESET);
    } else if (pwm < 0) {
        __HAL_TIM_SET_COMPARE(&htim1, TIM_CHANNEL_2, 1000 + pwm);
        HAL_GPIO_WritePin(MOTOR2_DIRECTION_GPIO_Port, MOTOR2_DIRECTION_Pin, GPIO_PIN_SET);
    } else {
        __HAL_TIM_SET_COMPARE(&htim1, TIM_CHANNEL_2, 0);
        HAL_GPIO_WritePin(MOTOR2_DIRECTION_GPIO_Port, MOTOR2_DIRECTION_Pin, GPIO_PIN_RESET);
    }
}

void Motor3Callback(double pwm)
{
    if (pwm > 0) {
        __HAL_TIM_SET_COMPARE(&htim1, TIM_CHANNEL_3, pwm);
        HAL_GPIO_WritePin(MOTOR3_DIRECTION_GPIO_Port, MOTOR3_DIRECTION_Pin, GPIO_PIN_RESET);
    } else if (pwm < 0) {
        __HAL_TIM_SET_COMPARE(&htim1, TIM_CHANNEL_3, 1000 + pwm);
        HAL_GPIO_WritePin(MOTOR3_DIRECTION_GPIO_Port, MOTOR3_DIRECTION_Pin, GPIO_PIN_SET);
    } else {
        __HAL_TIM_SET_COMPARE(&htim1, TIM_CHANNEL_3, 0);
        HAL_GPIO_WritePin(MOTOR3_DIRECTION_GPIO_Port, MOTOR3_DIRECTION_Pin, GPIO_PIN_RESET);
    }
}

void Motor4Callback(double pwm)
{
    if (pwm > 0) {
        __HAL_TIM_SET_COMPARE(&htim1, TIM_CHANNEL_4, pwm);
        HAL_GPIO_WritePin(MOTOR4_DIRECTION_GPIO_Port, MOTOR4_DIRECTION_Pin, GPIO_PIN_RESET);
    } else if (pwm < 0) {
        __HAL_TIM_SET_COMPARE(&htim1, TIM_CHANNEL_4, 1000 + pwm);
        HAL_GPIO_WritePin(MOTOR4_DIRECTION_GPIO_Port, MOTOR4_DIRECTION_Pin, GPIO_PIN_SET);
    } else {
        __HAL_TIM_SET_COMPARE(&htim1, TIM_CHANNEL_4, 0);
        HAL_GPIO_WritePin(MOTOR4_DIRECTION_GPIO_Port, MOTOR4_DIRECTION_Pin, GPIO_PIN_RESET);
    }
}

void RobotInit()
{
    encodingMotor1.SetPID(4, 0.4, 0);
    encodingMotor1.SetOutputRange(-1000, 1000);
    encodingMotor1.SetSpeed(0);
    encodingMotor1.SetCallback(Motor1Callback);
    encodingMotor1.SetReverse(true);

    encodingMotor2.SetPID(4, 0.4, 0);
    encodingMotor2.SetOutputRange(-1000, 1000);
    encodingMotor2.SetSpeed(0);
    encodingMotor2.SetCallback(Motor2Callback);

    encodingMotor3.SetPID(4, 0.4, 0);
    encodingMotor3.SetOutputRange(-1000, 1000);
    encodingMotor3.SetSpeed(0);
    encodingMotor3.SetCallback(Motor3Callback);
    encodingMotor3.SetReverse(true);

    encodingMotor4.SetPID(4, 0.4, 0);
    encodingMotor4.SetOutputRange(-1000, 1000);
    encodingMotor4.SetSpeed(0);
    encodingMotor4.SetCallback(Motor4Callback);

    mecanumMotion.SetEncodingMotor1(&encodingMotor1);
    mecanumMotion.SetEncodingMotor2(&encodingMotor2);
    mecanumMotion.SetEncodingMotor3(&encodingMotor3);
    mecanumMotion.SetEncodingMotor4(&encodingMotor4);
}

void RobotTick()
{
    short speed = 0;

    speed = (short) __HAL_TIM_GET_COUNTER(&htim2);
    __HAL_TIM_SET_COUNTER(&htim2, 0);
    encodingMotor1.AddPulse(speed);
    encodingMotor1.Tick();

    speed = (short) __HAL_TIM_GET_COUNTER(&htim3);
    __HAL_TIM_SET_COUNTER(&htim3, 0);
    encodingMotor2.AddPulse(speed);
    encodingMotor2.Tick();

    speed = (short) __HAL_TIM_GET_COUNTER(&htim4);
    __HAL_TIM_SET_COUNTER(&htim4, 0);
    encodingMotor3.AddPulse(speed);
    encodingMotor3.Tick();

    speed = (short) __HAL_TIM_GET_COUNTER(&htim8);
    __HAL_TIM_SET_COUNTER(&htim8, 0);
    encodingMotor4.AddPulse(speed);
    encodingMotor4.Tick();

}

void RobotTest()
{
    mecanumMotion.Move(30, 36000, 14000);
    mecanumMotion.Move(30, -36000, -14000);
}

void RobotMove(double speed, double xDis, double yDis)
{
    mecanumMotion.Move(speed, xDis, yDis);
}

void RobotMoveX(double speed)
{
    mecanumMotion.ClearSpeed();
    mecanumMotion.AddXSpeed(speed);
    mecanumMotion.CommitSpeed();
}

void RobotMoveY(double speed)
{
    mecanumMotion.ClearSpeed();
    mecanumMotion.AddYSpeed(speed);
    mecanumMotion.CommitSpeed();
}

void RobotMoveZ(double speed)
{
    mecanumMotion.ClearSpeed();
    mecanumMotion.AddZSpeed(speed);
    mecanumMotion.CommitSpeed();
}

void RobotStop()
{
    mecanumMotion.ClearSpeed();
    mecanumMotion.CommitSpeed();
}

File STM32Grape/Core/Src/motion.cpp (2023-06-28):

#include "motion.h"

namespace RDK
{

    MecanumMotion::MecanumMotion()
    {
        double wheelDirectionVectorLen = std::sqrt(2);
        wheelADirectionVector.first /= wheelDirectionVectorLen;
        wheelADirectionVector.second /= wheelDirectionVectorLen;
        wheelBDirectionVector.first /= wheelDirectionVectorLen;
        wheelBDirectionVector.second /= wheelDirectionVectorLen;
    }

    MecanumMotion::~MecanumMotion()
    {
    }

    void MecanumMotion::SetEncodingMotor1(EncodingMotor *motor)
    {
        this->motor1 = motor;
    }

    void MecanumMotion::SetEncodingMotor2(EncodingMotor *motor)
    {
        this->motor2 = motor;
    }

    void MecanumMotion::SetEncodingMotor3(EncodingMotor *motor)
    {
        this->motor3 = motor;
    }

    void MecanumMotion::SetEncodingMotor4(EncodingMotor *motor)
    {
        this->motor4 = motor;
    }

    void MecanumMotion::ClearSpeed()
    {
        motor1Speed = 0;
        motor2Speed = 0;
        motor3Speed = 0;
        motor4Speed = 0;
    }

    void MecanumMotion::AddXSpeed(double speed)
    {
        motor1Speed += speed;
        motor2Speed += speed;
        motor3Speed += speed;
        motor4Speed += speed;
    }

    void MecanumMotion::AddYSpeed(double speed)
    {
        motor1Speed -= speed;
        motor2Speed += speed;
        motor3Speed += speed;
        motor4Speed -= speed;
    }

    void MecanumMotion::AddZSpeed(double speed)
    {
        motor1Speed -= speed;
        motor2Speed += speed;
        motor3Speed -= speed;
        motor4Speed += speed;
    }

    void MecanumMotion::CommitSpeed()
    {
        if (motor1)
            motor1->SetSpeed(motor1Speed);
        if (motor2)
            motor2->SetSpeed(motor2Speed);
        if (motor3)
            motor3->SetSpeed(motor3Speed);
        if (motor4)
            motor4->SetSpeed(motor4Speed);
    }

    void MecanumMotion::SetPosPID(double p, double i, double d)
    {
        this->kp = p;
        this->ki = i;
        this->kd = d;
    }

    /*
     * @brief 2维平面内上下左右移动
     * @attention 调用此方法会一直阻塞到移动结束！
     * @param speed 移动速度
     * @param xDis x轴移动距离
     * @param yDis y轴移动距离
     */
    void MecanumMotion::Move(double speed, double xDis, double yDis)
    {
        PID motor1PosPID(RDK::PIDType::Pos, this->kp, this->ki, this->kd);
        PID motor2PosPID(RDK::PIDType::Pos, this->kp, this->ki, this->kd);
        PID motor3PosPID(RDK::PIDType::Pos, this->kp, this->ki, this->kd);
        PID motor4PosPID(RDK::PIDType::Pos, this->kp, this->ki, this->kd);
        if (speed < 0)
            speed = -speed;
        motor1PosPID.SetTotalErrorRange(minTotalError, maxTotalError);
        motor2PosPID.SetTotalErrorRange(minTotalError, maxTotalError);
        motor3PosPID.SetTotalErrorRange(minTotalError, maxTotalError);
        motor4PosPID.SetTotalErrorRange(minTotalError, maxTotalError);
        motor1PosPID.SetOutputRange(-speed, speed);
        motor2PosPID.SetOutputRange(-speed, speed);
        motor3PosPID.SetOutputRange(-speed, speed);
        motor4PosPID.SetOutputRange(-speed, speed);

        double motor1TargetDis = xDis * wheelADirectionVector.first + yDis * wheelADirectionVector.second;
        double motor2TargetDis = xDis * wheelBDirectionVector.first + yDis * wheelBDirectionVector.second;
        double motor3TargetDis = xDis * wheelBDirectionVector.first + yDis * wheelBDirectionVector.second;
        double motor4TargetDis = xDis * wheelADirectionVector.first + yDis * wheelADirectionVector.second;

        motor1->ClearPulse();
        motor2->ClearPulse();
        motor3->ClearPulse();
        motor4->ClearPulse();

        motor1PosPID.SetTarget(motor1TargetDis);
        motor2PosPID.SetTarget(motor2TargetDis);
        motor3PosPID.SetTarget(motor3TargetDis);
        motor4PosPID.SetTarget(motor4TargetDis);

        while (true)
        {
            if (std::fabs(motor1->GetPulse() - motor1TargetDis) < 5 &&
                std::fabs(motor2->GetPulse() - motor2TargetDis) < 5 &&
                std::fabs(motor3->GetPulse() - motor3TargetDis) < 5 &&
                std::fabs(motor4->GetPulse() - motor4TargetDis) < 5)
                break;
            motor1PosPID.SetInput(motor1->GetPulse());
            motor1PosPID.Tick();
            motor2PosPID.SetInput(motor2->GetPulse());
            motor2PosPID.Tick();
            motor3PosPID.SetInput(motor3->GetPulse());
            motor3PosPID.Tick();
            motor4PosPID.SetInput(motor4->GetPulse());
            motor4PosPID.Tick();

            ClearSpeed();
            motor1Speed += motor1PosPID.GetOutput();
            motor2Speed += motor2PosPID.GetOutput();
            motor3Speed += motor3PosPID.GetOutput();
            motor4Speed += motor4PosPID.GetOutput();
            CommitSpeed();
        }
        ClearSpeed();
        CommitSpeed();
    }

}

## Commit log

2023-06-09 3D模型
    [37GB电机支架 v2.f3d, 9轴IMU v2.f3d, DC模块 v2.f3d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]
2023-06-27 finish pid
2023-06-28 编码电机
2023-06-28 麦克纳姆轮速度控制
2023-06-28 二维平面上下左右移动
2023-06-28 上位机控制下位机运动
2023-06-28 舵机驱动
2023-06-28 机械臂求逆
